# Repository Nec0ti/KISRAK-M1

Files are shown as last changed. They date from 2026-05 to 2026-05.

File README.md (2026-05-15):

# KISRAK-M1 Motor Driver

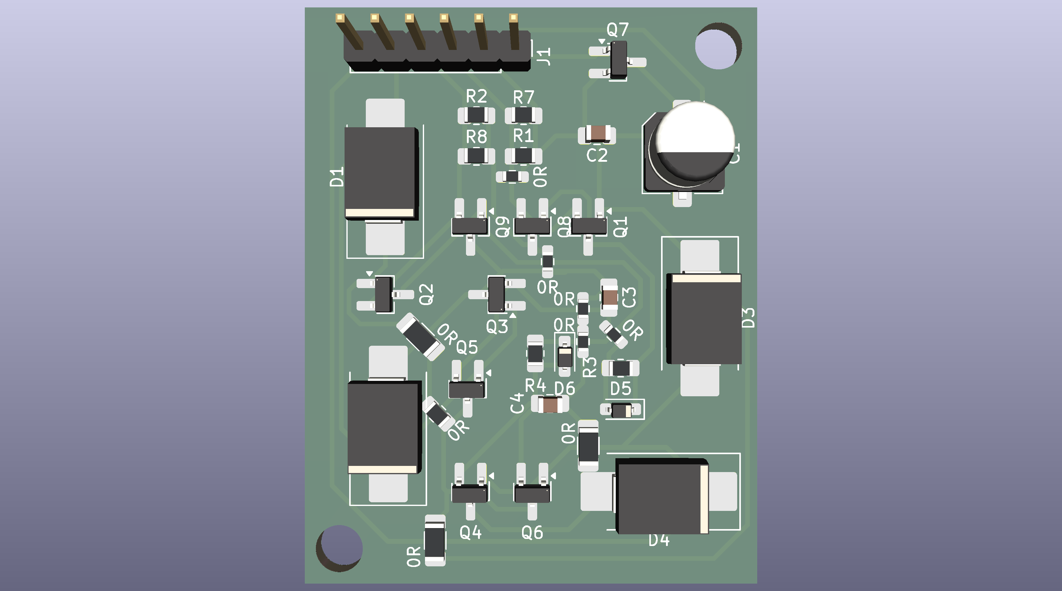
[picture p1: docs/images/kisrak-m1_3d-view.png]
KISRAK-M1 3D View


KISRAK-M1 is a high-efficiency, discrete H-Bridge motor driver designed for micro-robotics. 

## Technical Specifications
- **Type:** Discrete Complementary MOSFET H-Bridge.
- **MOSFETs:** UT2305G (P-Ch) & UTM2054G (N-Ch) logic-level pairs.
- **Logic Level:** 3.3V compatible (Tested with STM32).
- **Protection:** Passive Hardware Dead-Time & Reverse Polarity Protection.

## Passive Dead-Time Design
This project uses an RC-D circuit (47R, 2.2nF, 1N4148) to create asymmetrical switching times, preventing shoot-through without complex MCU PWM dead-time configuration.

## Documentation
For in-depth technical details, design philosophy, and fabrication guides, please refer to the [official documentation](docs/README.md).

## Micromouse Inspiration
To understand the competitive robotics context for which KISRAK-M1 is designed, watch this excellent overview of Micromouse competitions:

Micromouse Competition (https://www.youtube.com/watch?v=ZMQbHMgK2rw)

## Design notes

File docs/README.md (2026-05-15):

# KISRAK-M1 Documentation

Welcome to the official documentation for the KISRAK-M1 project. This document aims to provide a comprehensive and in-depth understanding of the KISRAK-M1 motor driver, covering its design philosophy, detailed hardware architecture, underlying physics, control mechanisms, fabrication guidelines, and validation procedures.

KISRAK-M1 is designed as a high-performance, open-source motor driver, specifically tailored for micro-robotic applications like Micromouse. My goal is not only to present "what" was built but also to elaborate on "why" specific design choices were made and the fundamental physical principles that govern its operation.

## Table of Contents

*   [Executive Summary & Project Motivation](01-Executive-Summary/index.html)
*   [Detailed Hardware Architecture (Sub-Systems)](02-Hardware-Architecture/index.html)
*   [The Physics of Dead-Time (Deep Dive)](03-Dead-Time-Physics/index.html)
*   [Signal Control & Firmware Interfacing](04-Signal-Control/index.html)
*   [DIY Fabrication & Reliability](05-DIY-Fabrication/index.html)
*   [Test & Validation](06-Test-Validation/index.html)

---
*This documentation is a living document and will be continuously updated.*

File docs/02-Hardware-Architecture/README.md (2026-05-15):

# 02 - Detailed Hardware Architecture (Sub-Systems)

This section delves into the intricate details of the KISRAK-M1's hardware architecture, breaking down each sub-system and explaining the design choices and their implications.

## Table of Contents

*   [Power Stage: MOSFET Selection and Thermal Efficiency](01-Power-Stage.html)
*   [Driver Stage: Totem-Pole Gate Drive](02-Driver-Stage.html)
*   [Protection Systems: Reverse Polarity and Inductive Kickback](03-Protection-Systems.html)

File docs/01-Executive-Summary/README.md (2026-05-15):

# 01 - Executive Summary & Project Motivation

This section provides an overview of the KISRAK-M1 project, outlining its core motivations, design philosophy, and the rationale behind key architectural decisions.

## Table of Contents

*   [Motor Driver Limitations in Robotics](01-Motor-Driver-Limits.html)
*   [KISRAK-M1's Micromouse Design Philosophy](02-Micromouse-Design-Philosophy.html)
*   [Why Discrete MOSFET Design?](03-Discrete-MOSFET-Choice.html)

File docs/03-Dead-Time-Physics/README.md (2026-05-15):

# 03 - The Physics of Dead-Time (Deep Dive)

Dead-time is a critical concept in H-bridge motor driver design. This section provides a deep dive into the physics behind dead-time, its calculation, and its importance in preventing shoot-through conditions.

## Table of Contents

*   [RC-D Circuit Time Constant Calculations](01-RC-D-Calculations.html)
*   [Asymmetric Switching: Rise Time vs. Fast Discharge](02-Asymmetric-Switching.html)
*   [Cross-Conduction (Shoot-through) Risk Analysis](03-Cross-Conduction-Analysis.html)

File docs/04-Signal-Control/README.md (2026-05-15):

# 04 - Signal Control & Firmware Interfacing

This section focuses on the control aspects of the KISRAK-M1, including PWM signal generation, duty cycle calculations, and how the driver interfaces with microcontrollers.

## Table of Contents

*   [PWM Frequency Selection (8kHz - 20kHz)](01-PWM-Frequency-Selection.html)
*   [Duty Cycle and Average Voltage Calculation](02-Duty-Cycle-Voltage.html)
*   [Control Logic Table for MCUs](03-Control-Logic-Table.html)

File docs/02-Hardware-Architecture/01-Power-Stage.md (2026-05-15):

# Power Stage: MOSFET Selection and Thermal Efficiency

The power stage of the KISRAK-M1 motor driver is a critical component, directly responsible for delivering current to the motor. It utilizes a full H-bridge configuration built with discrete P-Channel (UT2305G) and N-Channel (UTM2054G) MOSFETs. The selection of these specific MOSFETs is driven by a careful balance of performance, efficiency, and cost, with a strong emphasis on minimizing power losses and managing thermal dissipation.

## MOSFET Selection Criteria:

1.  **Voltage Rating ($V_{DS}$):** The drain-source voltage rating must be sufficiently higher than the maximum expected battery voltage to provide a safety margin against voltage spikes and transients. For KISRAK-M1, operating typically from a 1S or 2S LiPo battery (3.7V - 8.4V nominal), MOSFETs with a $V_{DS}$ rating of 20V or 30V are generally suitable. The UT2305G (P-Channel) and UTM2054G (N-Channel) both offer a 20V rating, providing an adequate margin.
2.  **Current Rating ($I_D$):** The continuous drain current rating must exceed the maximum expected motor current. Micromouse motors can draw significant peak currents during acceleration. The selected MOSFETs offer continuous drain currents (e.g., UT2305G: -4.6A, UTM2054G: 5.3A at $V_{GS}=4.5V$), which are sufficient for typical Micromouse applications, especially when considering the pulsed nature of PWM.
3.  **Gate-Source Voltage ($V_{GS}$):** The MOSFETs must be fully turned on (saturated) by the gate drive voltage provided by the microcontroller or gate driver. Both selected MOSFETs are "logic-level" compatible, meaning they can be fully turned on with a $V_{GS}$ as low as 2.5V or 4.5V, making them suitable for direct driving from a 3.3V or 5V microcontroller.
4.  **Gate Charge ($Q_g$):** This parameter is crucial for switching losses. A lower gate charge means less energy is required to charge and discharge the gate capacitance, leading to faster switching times and reduced switching losses, especially at higher PWM frequencies.
5.  **On-State Resistance ($R_{DS(on)}$):** This is arguably the most critical parameter for thermal efficiency in the power stage.

## The Impact of $R_{DS(on)}$ on Thermal Efficiency:

$R_{DS(on)}$ is the resistance between the drain and source terminals of a MOSFET when it is fully turned on. When current flows through the MOSFET in its on-state, power is dissipated as heat due to this resistance. This power loss is calculated by:

$$P_{conduction} = I_D^2 \times R_{DS(on)}$$

Where:
*   $P_{conduction}$ is the power dissipated as heat due to conduction.
*   $I_D$ is the drain current flowing through the MOSFET.
*   $R_{DS(on)}$ is the on-state resistance.

**Why lower $R_{DS(on)}$ is crucial:**

*   **Reduced Heat Generation:** A lower $R_{DS(on)}$ directly leads to less power being converted into heat for a given current. This is vital for compact designs like KISRAK-M1, where heat dissipation can be challenging.
*   **Improved Efficiency:** Less power lost as heat means more power delivered to the motor, increasing the overall efficiency of the motor driver. This translates to longer battery life and better performance.
*   **Prevention of Thermal Runaway:** Excessive heat can increase $R_{DS(on)}$ (for N-channel MOSFETs, $R_{DS(on)}$ typically increases with temperature), leading to a positive feedback loop where more heat generates more resistance, leading to even more heat. This can eventually destroy the MOSFET. Selecting MOSFETs with very low $R_{DS(on)}$ helps mitigate this risk.
*   **Smaller Heatsinking Requirements:** With less heat generated, the need for large heatsinks or extensive copper pours for thermal dissipation is reduced, allowing for a more compact PCB design.

### Selected MOSFETs:

*   **P-Channel MOSFET (High-Side): UT2305G**
    *   $V_{DS}$: -20V
    *   $I_D$: -4.6A
    *   $R_{DS(on)}$: 45mΩ @ $V_{GS}=-4.5V$, 65mΩ @ $V_{GS}=-2.5V$
    *   Datasheet: [UT2305G Datasheet](../datasheets/ut2305g-datasheet.pdf)

*   **N-Channel MOSFET (Low-Side): UTM2054G**
    *   $V_{DS}$: 20V
    *   $I_D$: 5.3A
    *   $R_{DS(on)}$: 25mΩ @ $V_{GS}=4.5V$, 35mΩ @ $V_{GS}=2.5V$
    *   Datasheet: [UTM2054G Datasheet](../datasheets/utm2054g-datasheet.pdf)

The chosen MOSFETs offer a good balance of low $R_{DS(on)}$ for their package size (SOT-23), sufficient current and voltage ratings, and logic-level compatibility, making them ideal for the KISRAK-M1's high-performance, compact design. The difference in $R_{DS(on)}$ between P-channel and N-channel MOSFETs is typical, as P-channel devices generally have higher on-resistance for a given die size due to the lower mobility of holes compared to electrons. This is why N-channel MOSFETs are preferred for low-side switching where possible.

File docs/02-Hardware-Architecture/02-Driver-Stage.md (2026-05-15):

# Driver Stage: Totem-Pole Gate Drive

The efficiency and reliability of a MOSFET H-bridge largely depend on how quickly and effectively the MOSFETs are switched between their ON and OFF states. This is the primary function of the gate driver stage. KISRAK-M1 employs a discrete **Totem-Pole gate driver** configuration using a complementary BJT pair (MMBT2222A NPN and MMBT2907A PNP) to manage the gate charge and discharge currents of the power MOSFETs.

<h2>The Need for a Gate Driver:</h2>

MOSFETs are voltage-controlled devices, but their gates exhibit significant capacitance ($C_{iss}$, $C_{rss}$, $C_{oss}$). To switch a MOSFET quickly, this gate capacitance must be charged and discharged rapidly. The current required to do this is known as the **gate charge current**. A microcontroller's GPIO pin, while capable of providing a voltage, typically has limited current sourcing/sinking capability (e.g., a few tens of mA). This is often insufficient to charge/discharge the MOSFET gate capacitance quickly enough, leading to:

*   **Slow Switching Times:** Prolonged transitions between ON and OFF states.
*   **Increased Switching Losses:** During the transition, the MOSFET is neither fully ON (low $R_{DS(on)}$) nor fully OFF (high impedance), resulting in significant power dissipation ($P_{switching} = V_{DS} \times I_D \times t_{transition} \times f_{PWM}$).
*   **Excessive Heat Generation:** Higher switching losses contribute to overall heat, potentially leading to thermal runaway.

<h2>Totem-Pole Configuration:</h2>

The Totem-Pole driver acts as a current buffer, amplifying the weak signal from the microcontroller to provide the necessary high current pulses to the MOSFET gate.

<h3>How it Works:</h3>

A typical Totem-Pole driver consists of an NPN transistor (e.g., MMBT2222A) and a PNP transistor (e.g., MMBT2907A) arranged in series, with their collectors connected to the MOSFET gate.

*   **Turning ON the MOSFET (Charging the Gate):**
    *   When the input signal from the MCU goes HIGH, the NPN transistor (MMBT2222A) turns ON.
    *   The PNP transistor (MMBT2907A) turns OFF.
    *   Current flows from the supply voltage (e.g., 5V or 3.3V) through a current-limiting resistor (if present) and the NPN transistor into the MOSFET gate, rapidly charging its capacitance. This pulls the gate voltage HIGH, turning the MOSFET ON.

*   **Turning OFF the MOSFET (Discharging the Gate):**
    *   When the input signal from the MCU goes LOW, the NPN transistor turns OFF.
    *   The PNP transistor turns ON.
    *   The MOSFET gate capacitance rapidly discharges through the PNP transistor to ground. This pulls the gate voltage LOW, turning the MOSFET OFF.

<h3>Gate Charge/Discharge Currents:</h3>

The BJT pair in the Totem-Pole configuration can source and sink much higher currents than a typical MCU GPIO. For instance, the MMBT2222A and MMBT2907A can handle continuous collector currents of up to 600mA. This high current capability allows for very fast charging and discharging of the MOSFET gate capacitance.

The peak gate current ($I_{G,peak}$) can be approximated by Ohm's law during the charging/discharging phase, considering the gate driver's output impedance and any series gate resistors. A higher peak current leads to a faster voltage slew rate at the gate ($dV_{GS}/dt$), which in turn reduces the switching time.

<h2>Benefits of Totem-Pole Gate Drive in KISRAK-M1:</h2>

1.  **Fast Switching:** By providing high peak gate currents, the Totem-Pole driver ensures rapid charging and discharging of the MOSFET gates, minimizing switching losses.
2.  **Reduced Power Dissipation:** Faster transitions mean the MOSFET spends less time in the linear region, where it dissipates the most power. This significantly improves overall efficiency and reduces heat generation in the power MOSFETs.
3.  **Improved EMI Performance:** Sharper switching edges can sometimes lead to increased EMI, but controlled fast switching can also reduce the energy content in the switching transitions, which can be beneficial.
4.  **Robustness:** The discrete BJT solution is robust and can be tailored for specific voltage levels and current requirements.

<h3>Selected BJTs:</h3>

*   **NPN Transistor: MMBT2222A**
    *   $V_{CEO}$: 40V
    *   $I_C$: 600mA
    *   Datasheet: [MMBT2222A Datasheet](../datasheets/2n2222-datasheet.pdf)

*   **PNP Transistor: MMBT2907A**
    *   $V_{CEO}$: -40V
    *   $I_C$: -600mA
    *   Datasheet: [MMBT2907A Datasheet](../datasheets/2n2907-datasheet.pdf)

These general-purpose BJTs are well-suited for the Totem-Pole configuration, offering sufficient current handling and switching speed for the KISRAK-M1's gate drive requirements. The use of discrete BJTs also contributes to the educational value, allowing for a clear understanding of the gate drive mechanism.

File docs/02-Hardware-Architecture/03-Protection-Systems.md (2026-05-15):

# Protection Systems: Reverse Polarity and Inductive Kickback

Robust protection systems are paramount for the reliability and longevity of any motor driver, especially in applications where power sources can be inadvertently connected incorrectly or where inductive loads are switched rapidly. KISRAK-M1 incorporates two key protection mechanisms: reverse polarity protection and inductive kickback suppression.

## Q7 Reverse Polarity Protection:

Accidental reverse connection of the battery is a common mistake that can instantly destroy unprotected electronic circuits. KISRAK-M1 employs a P-Channel MOSFET (Q7) for reverse polarity protection, offering a more efficient solution than a simple series diode.

### Mechanism:

A P-Channel MOSFET is placed in series with the positive power supply line, with its drain connected to the battery's positive terminal and its source connected to the rest of the circuit's positive rail. The gate of the P-Channel MOSFET is connected to ground (or a voltage divider that ensures $V_{GS}$ is appropriate).

*   **Correct Polarity Connection:**
    *   When the battery is connected correctly, the positive terminal is at a higher potential than the gate (which is at ground).
    *   This creates a negative $V_{GS}$ (e.g., $V_{GS} = V_{gate} - V_{source} = 0V - V_{battery}$).
    *   If the magnitude of this negative $V_{GS}$ is greater than the MOSFET's threshold voltage ($V_{GS(th)}$), the P-Channel MOSFET turns ON, allowing current to flow from the battery to the circuit.
    *   The MOSFET's body diode will conduct initially, and once the MOSFET turns on, current flows through the channel, bypassing the body diode and significantly reducing voltage drop and power loss compared to a standard diode.

*   **Reverse Polarity Connection:**
    *   When the battery is connected in reverse, the positive terminal of the battery (now effectively ground) is connected to the drain, and the negative terminal (now at a negative potential) is connected to the source.
    *   The gate is still at ground.
    *   In this scenario, the $V_{GS}$ becomes positive (e.g., $V_{GS} = V_{gate} - V_{source} = 0V - (-V_{battery}) = +V_{battery}$).
    *   A positive $V_{GS}$ keeps the P-Channel MOSFET firmly OFF.
    *   Crucially, the body diode of the P-Channel MOSFET will be reverse-biased, preventing current flow into the circuit. The circuit remains protected.

### Advantages over Series Diode:

*   **Lower Voltage Drop:** A P-Channel MOSFET in its ON state has a very low $R_{DS(on)}$, resulting in a minimal voltage drop across it (typically tens of millivolts). A standard silicon diode, in contrast, has a forward voltage drop of 0.7V or more, leading to significant power loss and heat generation, especially at higher currents.
*   **Higher Efficiency:** Reduced voltage drop means less power is wasted as heat, improving the overall efficiency of the system.
*   **Less Heat:** Lower power dissipation means less heat generated, simplifying thermal management.

## SS34 Schottky Diodes for Inductive Kickback Suppression:

Motors are inductive loads. When the current flowing through an inductor is rapidly switched off (e.g., when a MOSFET in the H-bridge turns off), the inductor resists this change by generating a large voltage spike (known as "inductive kickback" or "flyback voltage") with a polarity that tries to maintain the current flow. This voltage spike can easily exceed the breakdown voltage of the MOSFETs, leading to their destruction.

KISRAK-M1 utilizes SS34 Schottky diodes as **freewheeling diodes** (also known as flyback diodes or snubber diodes) to protect the MOSFETs from these destructive voltage spikes.

### Mechanism:

In an H-bridge, each MOSFET has a freewheeling diode connected in parallel, but in reverse bias across its drain and source. When a MOSFET turns off, and the motor's inductance tries to maintain current flow, the voltage across the MOSFET rises. As soon as this voltage exceeds the forward voltage of the freewheeling diode, the diode turns ON, providing a path for the inductive current to circulate. This clamps the voltage across the MOSFET to a safe level (approximately $V_{supply} + V_{diode\_forward\_drop}$).

### Why Schottky Diodes (SS34)?

Schottky diodes are preferred over standard silicon diodes for freewheeling applications due to their:

1.  **Low Forward Voltage Drop ($V_F$):** SS34 has a typical $V_F$ of around 0.5V. A lower $V_F$ means less power is dissipated in the diode itself and, more importantly, the voltage spike seen by the MOSFET is clamped to a lower value, providing better protection.
2.  **Fast Recovery Time:** Schottky diodes have very fast reverse recovery times (ideally zero). This is crucial in high-frequency PWM applications, as it prevents current spikes during the transition when the diode switches from conducting to blocking. A slow recovery diode can momentarily act as a short circuit, leading to shoot-through or increased switching losses.

### Inductive Kickback Suppression Mathematics:

The energy stored in an inductor is given by:
$$E_L = \frac{1}{2} L I^2$$
Where:
*   $E_L$ is the stored energy in Joules.
*   $L$ is the inductance in Henrys.
*   $I$ is the current in Amperes.

When the switch opens, this energy must be dissipated. Without a freewheeling diode, the voltage across the switch can rise to very high levels, limited only by parasitic capacitances and the breakdown voltage of the switch. With a freewheeling diode, the inductive current is diverted through the diode and the power supply (or another part of the H-bridge), dissipating the energy safely.

The voltage across the MOSFET when the diode conducts will be approximately:
$$V_{MOSFET} \approx V_{supply} + V_{F(diode)}$$
This ensures that the MOSFET's $V_{DS}$ rating is not exceeded.

### Selected Schottky Diode: SS34

*   $V_{RRM}$: 40V
*   $I_F$: 3A
*   $V_F$: 0.5V @ 3A
*   Datasheet: [SS34 Datasheet](../datasheets/ss34-datasheet.pdf)

The SS34 provides excellent protection against inductive kickback due to its low forward voltage and fast switching characteristics, ensuring the longevity and reliability of the KISRAK-M1 motor driver.

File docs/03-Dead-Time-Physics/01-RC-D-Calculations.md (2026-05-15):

# RC-D Circuit Time Constant Calculations

In an H-bridge motor driver, **dead-time** is a crucial concept referring to a short delay intentionally inserted between the turn-off of one MOSFET and the turn-on of its complementary MOSFET in the same half-bridge leg. This delay is essential to prevent **cross-conduction** (also known as shoot-through), a condition where both MOSFETs in a half-bridge are simultaneously ON, creating a direct short circuit across the power supply.

KISRAK-M1 implements a passive dead-time generation circuit using an RC-D (Resistor-Capacitor-Diode) network. This circuit, typically consisting of a 47Ω resistor, a 2.2nF capacitor, and a 1N4148 small signal diode, is placed in the gate drive path to introduce the necessary delay.

## The RC-D Network:

The RC-D circuit is designed to create an asymmetric delay in the gate signal.

*   **Resistor (R):** 47Ω
*   **Capacitor (C):** 2.2nF
*   **Diode (D):** 1N4148

### Time Constant ($\tau$) Calculation:

The fundamental characteristic of an RC circuit is its **time constant ($\tau$)**, which represents the time it takes for the capacitor voltage to reach approximately 63.2% of its final value during charging or to discharge to 36.8% of its initial value. It is calculated as:

$$\tau = R \times C$$

For the KISRAK-M1's RC-D circuit:
*   $R = 47 \, \Omega$
*   $C = 2.2 \, nF = 2.2 \times 10^{-9} \, F$

Therefore, the time constant is:
$$\tau = 47 \, \Omega \times 2.2 \times 10^{-9} \, F = 103.4 \times 10^{-9} \, s = 103.4 \, ns$$

This time constant of approximately 103.4 nanoseconds is a key parameter in determining the dead-time. It dictates the charging time of the capacitor, which in turn influences the turn-on delay of the MOSFET.

## Role of the Diode (1N4148):

The 1N4148 small signal diode is critical for creating the **asymmetric switching** behavior.

*   **Charging (Turn-ON Delay):** When the gate drive signal goes high, the capacitor charges through the resistor (R). The diode is reverse-biased during this phase (or has minimal effect if placed in parallel with R for charging), and the charging path is primarily through R and C. The time constant $\tau = R \times C$ governs this charging.
*   **Discharging (Turn-OFF Speed):** When the gate drive signal goes low, the capacitor needs to discharge quickly to turn off the MOSFET. The diode is placed in parallel with the resistor, but oriented to provide a low-resistance path for the discharge current, effectively bypassing the resistor. This allows the capacitor to discharge much faster than it charged, leading to a rapid turn-off.

The 1N4148 is a fast switching diode, which is important for ensuring that the discharge path is indeed low impedance and that the diode itself does not introduce significant delays.

## Importance of Dead-Time:

The calculated time constant and the asymmetric switching provided by the RC-D network directly contribute to the dead-time. This dead-time ensures that:

1.  One MOSFET is fully OFF before its complementary MOSFET begins to turn ON.
2.  This prevents shoot-through currents, which can damage the MOSFETs and waste significant power.

The precise value of dead-time is a trade-off. Too short, and shoot-through can occur. Too long, and efficiency can be reduced due to increased conduction losses in the body diodes of the MOSFETs during the dead-time period. The 103.4ns time constant provides a suitable delay for the chosen MOSFETs and switching frequencies in KISRAK-M1.

Datasheet for 1N4148: [1N4148WS Datasheet](../datasheets/1n4148ws-datasheet.pdf)

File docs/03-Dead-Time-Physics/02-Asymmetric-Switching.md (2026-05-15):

# Asymmetric Switching: Rise Time Delay vs. Fast Discharge Mechanism

The KISRAK-M1 motor driver employs an RC-D network in its gate drive stage to achieve **asymmetric switching**. This means that the turn-on time (rise time) of the MOSFET is intentionally made slower than its turn-off time (fall time). This asymmetry is a deliberate design choice to implement dead-time and prevent shoot-through, while still ensuring efficient operation.

## The RC-D Network for Asymmetry:

As discussed in the previous section, the RC-D circuit consists of a resistor (R), a capacitor (C), and a diode (D). The key to asymmetric switching lies in the diode's orientation and its interaction with the resistor and capacitor during charging and discharging cycles.

### 1. Rising Edge Delay (Slower Turn-ON):

When the input signal to the gate driver (from the MCU or a preceding stage) transitions from LOW to HIGH, the MOSFET gate needs to be charged to its turn-on threshold.

*   During this phase, the capacitor (C) charges through the resistor (R).
*   The diode (D) is typically reverse-biased or configured such that it does not provide a low-impedance path for charging.
*   The charging path is primarily defined by R and C, creating a time constant $\tau = R \times C$.
*   This RC time constant introduces a delay in the rising edge of the gate voltage, effectively slowing down the MOSFET's turn-on. The gate voltage will rise exponentially towards the supply voltage, taking several time constants to reach full turn-on.

This intentional delay in the turn-on of one MOSFET provides the necessary dead-time, ensuring that its complementary MOSFET in the half-bridge has sufficient time to fully turn off before the new MOSFET begins to conduct.

### 2. Fast Discharge Mechanism (Faster Turn-OFF):

When the input signal transitions from HIGH to LOW, the MOSFET gate needs to be rapidly discharged to turn the MOSFET off quickly.

*   During this phase, the capacitor (C) needs to discharge.
*   The diode (D) is now forward-biased, providing a low-resistance path for the discharge current. This path effectively bypasses the resistor (R).
*   Since the discharge path has a much lower equivalent resistance (primarily the forward resistance of the diode and the output impedance of the gate driver's sink stage), the capacitor discharges much faster.
*   This rapid discharge causes the gate voltage to fall quickly, leading to a fast turn-off of the MOSFET.

## Why Asymmetric Switching is Desirable:

1.  **Dead-Time Generation:** The primary reason for asymmetric switching is to create a reliable dead-time. By delaying the turn-on, I guarantee that there's a period where both MOSFETs in a half-bridge are OFF, preventing shoot-through.
2.  **Preventing Cross-Conduction:** A fast turn-off is crucial to quickly remove charge from the gate and ensure the MOSFET is non-conductive before its counterpart turns on. The slower turn-on then adds an additional safety margin.
3.  **Efficiency Considerations:** While a slower turn-on might seem counter-intuitive for efficiency (as it increases switching losses during turn-on), the overall benefit of preventing shoot-through (which causes catastrophic losses) far outweighs this. Moreover, the fast turn-off helps to minimize switching losses during the turn-off transition.
4.  **Miller Effect Mitigation:** During the turn-on transition, the MOSFET experiences the Miller effect, where the gate-drain capacitance ($C_{GD}$) is effectively multiplied, requiring more charge to change the gate voltage. A robust gate driver with asymmetric characteristics helps manage this by providing sufficient current for both charging and rapid discharging of the gate.

The 1N4148 diode, with its fast switching characteristics, is well-suited for this role, ensuring that the discharge path is indeed low impedance and that the diode itself does not introduce significant delays. This carefully engineered asymmetric switching ensures both the safety and efficiency of the KISRAK-M1 H-bridge.

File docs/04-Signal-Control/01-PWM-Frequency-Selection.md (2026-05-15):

# PWM Frequency Selection: Why 8kHz - 20kHz is Ideal

Pulse Width Modulation (PWM) is the fundamental technique I use in KISRAK-M1 to control the speed and direction of DC motors. The choice of PWM frequency is a critical design parameter that impacts motor performance, efficiency, audible noise, and electromagnetic interference (EMI). For KISRAK-M1, I have selected an ideal PWM frequency range of 8kHz to 20kHz based on a balance of these factors.

## Factors Influencing PWM Frequency Selection:

1.  **Audible Noise:**
    *   Human hearing typically ranges from 20Hz to 20kHz.
    *   PWM frequencies below 8kHz can often produce an audible whining or buzzing sound from the motor, which can be undesirable in many applications, especially in quiet environments or for user experience.
    *   By selecting a frequency above 8kHz, the switching noise is pushed towards the upper limit of human hearing, making it less noticeable or inaudible. Frequencies above 20kHz are generally considered ultrasonic and completely inaudible to humans.

2.  **Motor Inductance and Current Ripple:**
    *   DC motors are inductive loads. When a PWM voltage is applied, the motor's inductance smooths out the current, preventing it from rising and falling instantaneously.
    *   A higher PWM frequency results in a smaller current ripple (peak-to-peak variation in motor current).
    *   **Benefits of smaller current ripple:**
        *   **Reduced Motor Heating:** Large current ripples increase $I^2 R$ losses in the motor windings, leading to more heat.
        *   **Smoother Operation:** Less ripple results in smoother torque delivery and reduced vibrations.
        *   **Improved Efficiency:** Lower ripple current generally means better motor efficiency.
    *   However, excessively high frequencies can lead to increased switching losses in the MOSFETs (see point 3).

3.  **MOSFET Switching Losses:**
    *   Every time a MOSFET switches (turns ON or OFF), there are associated switching losses. These losses are proportional to the switching frequency.
    *   $$P_{switching} = (E_{on} + E_{off}) \times f_{PWM}$$
        Where $E_{on}$ and $E_{off}$ are the energy lost during turn-on and turn-off transitions, respectively.
    *   As the PWM frequency increases, switching losses increase. This generates more heat in the MOSFETs, potentially reducing efficiency and requiring more robust thermal management.
    *   A balance must be struck: high enough frequency for low audible noise and current ripple, but not so high that MOSFETs overheat.

4.  **Microcontroller Capabilities:**
    *   The chosen PWM frequency must be achievable by the microcontroller (MCU) generating the PWM signal. Most modern MCUs (like STM32) can easily generate PWM signals in the 8kHz-20kHz range with sufficient resolution (e.g., 8-bit or 10-bit duty cycle).
    *   Higher frequencies demand faster clock speeds and more sophisticated timer peripherals, which might limit duty cycle resolution.

5.  **Electromagnetic Interference (EMI):**
    *   Rapid switching of high currents can generate EMI. Higher frequencies can sometimes lead to more challenging EMI suppression, as the energy content shifts to higher frequency bands. However, well-controlled switching transitions (as achieved with the Totem-Pole driver) can help manage EMI.

## Why 8kHz - 20kHz is Ideal for KISRAK-M1:

*   **8kHz as a Lower Bound:** This frequency is generally considered the minimum to push most of the audible switching noise out of the most sensitive human hearing range. It provides a good balance for applications where some faint noise might be acceptable, but efficiency is paramount.
*   **20kHz as an Upper Bound:** This frequency is at the very edge of human hearing, making the motor virtually silent. It also provides a good balance with MOSFET switching losses for the chosen discrete components (UT2305G, UTM2054G) and their gate drive characteristics. Beyond 20kHz, the increase in switching losses often outweighs the benefits of further reduced current ripple or inaudibility for typical Micromouse motors.

This range ensures a quiet, efficient, and responsive motor control experience, perfectly suited for the demanding environment of Micromouse robotics. The KISRAK-M1's design, with its optimized gate drive, is capable of handling these frequencies effectively.

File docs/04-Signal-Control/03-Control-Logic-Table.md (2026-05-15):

# Control Logic Table for MCUs

Interfacing the KISRAK-M1 motor driver with a microcontroller (MCU) like an STM32 requires a clear understanding of the control signals needed to achieve desired motor movements. The KISRAK-M1 H-bridge is designed to be controlled by two PWM signals and two direction signals per motor, or a simplified two-pin control if the MCU can generate complementary PWM with dead-time. For simplicity and maximum flexibility, I'll consider a common four-pin control scheme per H-bridge, where two pins control the high-side MOSFETs and two pins control the low-side MOSFETs.

However, a more common and efficient approach for a full H-bridge is to use two PWM signals (one for each half-bridge) and two direction pins, or even just two PWM pins if the driver handles the complementary logic internally. Given the discrete nature of KISRAK-M1, the most direct control involves setting the gate signals for each of the four MOSFETs.

Let's define the control pins for one motor (one H-bridge):

*   `PWM_A`: Controls the high-side P-Channel MOSFET (e.g., Q1) and low-side N-Channel MOSFET (e.g., Q3) of one half-bridge.
*   `PWM_B`: Controls the high-side P-Channel MOSFET (e.g., Q2) and low-side N-Channel MOSFET (e.g., Q4) of the other half-bridge.

The KISRAK-M1 uses a complementary drive scheme where for each half-bridge, when the high-side P-channel is ON, the low-side N-channel is OFF, and vice-versa, with dead-time in between. The input to the Totem-Pole driver will determine the state of the MOSFETs.

Let's assume a simplified control where two input pins (`IN1`, `IN2`) from the MCU control the direction and speed of one motor. The internal logic of the KISRAK-M1 (via the Totem-Pole drivers and dead-time circuits) will then generate the appropriate gate signals for the four power MOSFETs.

## Simplified Control Logic (Two-Pin Input per Motor):

This table illustrates how two input pins from an MCU can control the direction and speed of a single motor connected to the KISRAK-M1 H-bridge. The PWM signal is applied to one of the input pins, while the other is held HIGH or LOW to set the direction.

| `IN1` (MCU Pin) | `IN2` (MCU Pin) | Motor Action |
| :--- | :--- | :--- |
| PWM | LOW | Motor rotates in Direction 1 (Speed controlled by PWM duty cycle) |
| LOW | PWM | Motor rotates in Direction 2 (Speed controlled by PWM duty cycle) |
| HIGH | HIGH | Motor Brake (Fast Decay / Short Brake) |
| LOW | LOW | Motor Freewheel (Coast / Slow Decay) |

### Explanation:

*   **PWM / LOW (Direction 1):** When `IN1` receives a PWM signal and `IN2` is held LOW, the H-bridge is configured to drive the motor in one direction. The duty cycle of the PWM on `IN1` determines the average voltage applied to the motor, thus controlling its speed.
*   **LOW / PWM (Direction 2):** Conversely, when `IN2` receives a PWM signal and `IN1` is held LOW, the motor rotates in the opposite direction, with speed controlled by the PWM on `IN2`.
*   **HIGH / HIGH (Fast Decay / Short Brake):** Both inputs HIGH effectively turns on both low-side MOSFETs (or high-side, depending on the exact internal logic of the driver stage), shorting the motor terminals. This provides a strong, rapid braking action by dissipating the motor's kinetic energy as heat in its windings.
*   **LOW / LOW (Slow Decay / Coast):** Both inputs LOW effectively turns off all active drive to the motor, allowing it to freewheel. The motor's back-EMF will circulate current through the freewheeling diodes and the low-side MOSFETs (if they are configured to be ON during this state), leading to a slower deceleration.

## Detailed Control Logic (Four-Pin Input per Motor - for direct gate control understanding):

For a deeper understanding, if the MCU were to directly control the gate drivers for each of the four MOSFETs in the H-bridge (assuming `GH1`, `GL1` for one half-bridge and `GH2`, `GL2` for the other, where `G` is Gate, `H` is High-side, `L` is Low-side, and 1/2 denote the half-bridge):

| `GH1` | `GL1` | `GH2` | `GL2` | Motor Action |
| :---- | :---- | :---- | :---- | :--- |
| PWM | LOW | LOW | HIGH  | Motor rotates in Direction 1 (Speed controlled by PWM) |
| LOW | HIGH  | PWM | LOW | Motor rotates in Direction 2 (Speed controlled by PWM) |
| LOW | HIGH  | LOW | HIGH  | Motor Brake (Fast Decay) |
| HIGH  | LOW | HIGH  | LOW | Motor Brake (Fast Decay) |
| LOW | LOW | LOW | LOW | Motor Freewheel (Coast) |

*Note: This table assumes active-high logic for N-channel MOSFETs and active-low for P-channel MOSFETs, and that the PWM is applied to the appropriate high-side or low-side switch for the desired direction. The actual implementation in KISRAK-M1 uses the Totem-Pole drivers to translate simpler MCU signals into the complex gate drive waveforms, including dead-time.*

Firmware developers should refer to the KISRAK-M1 schematic to understand the exact mapping of MCU pins to the driver's input signals. The simplified two-pin control per motor is generally preferred as it reduces the number of GPIOs required and offloads some of the complex timing (like dead-time generation) to the hardware.

This control logic forms the basis for implementing various motor control algorithms, including PID control for speed and position, crucial for high-performance robotic applications like Micromouse.

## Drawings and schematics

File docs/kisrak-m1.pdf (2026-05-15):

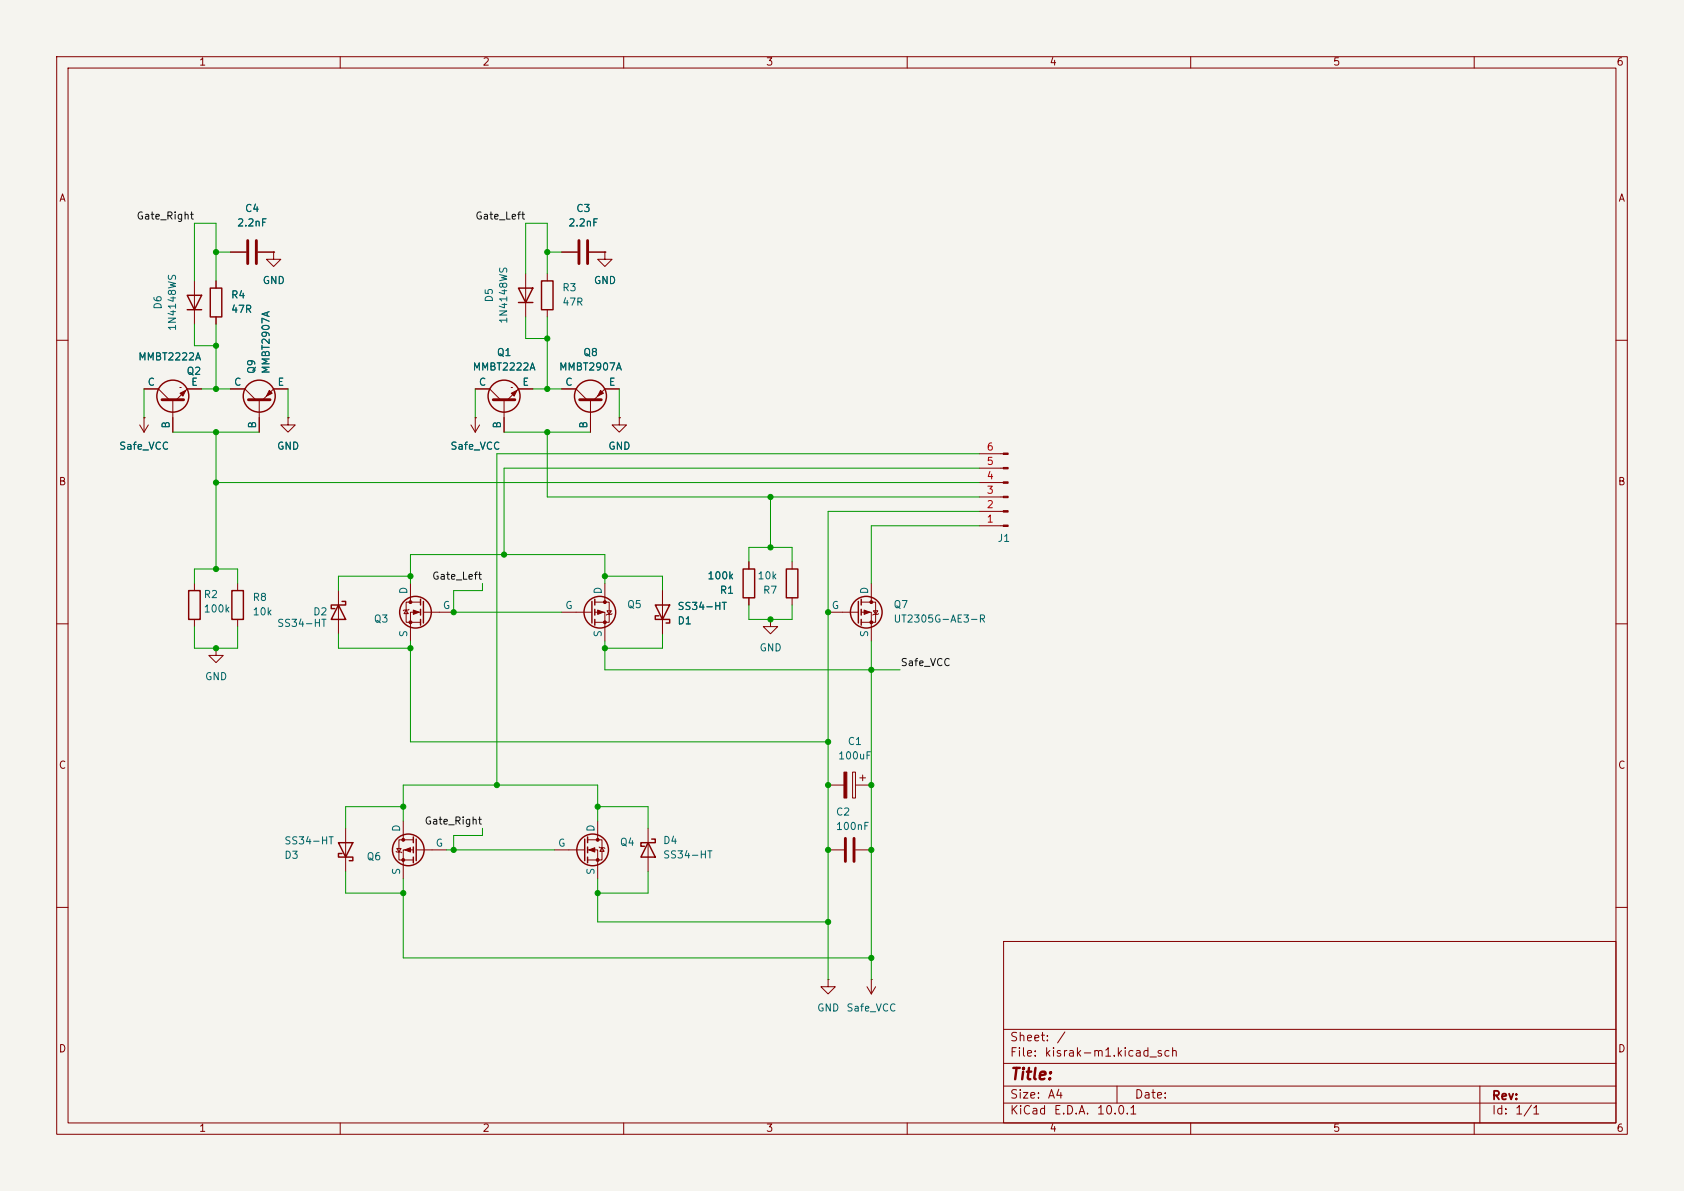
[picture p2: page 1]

Size: A4 | Rev:
KiCad E.D.A. 10.0.1 | Id: 1/1

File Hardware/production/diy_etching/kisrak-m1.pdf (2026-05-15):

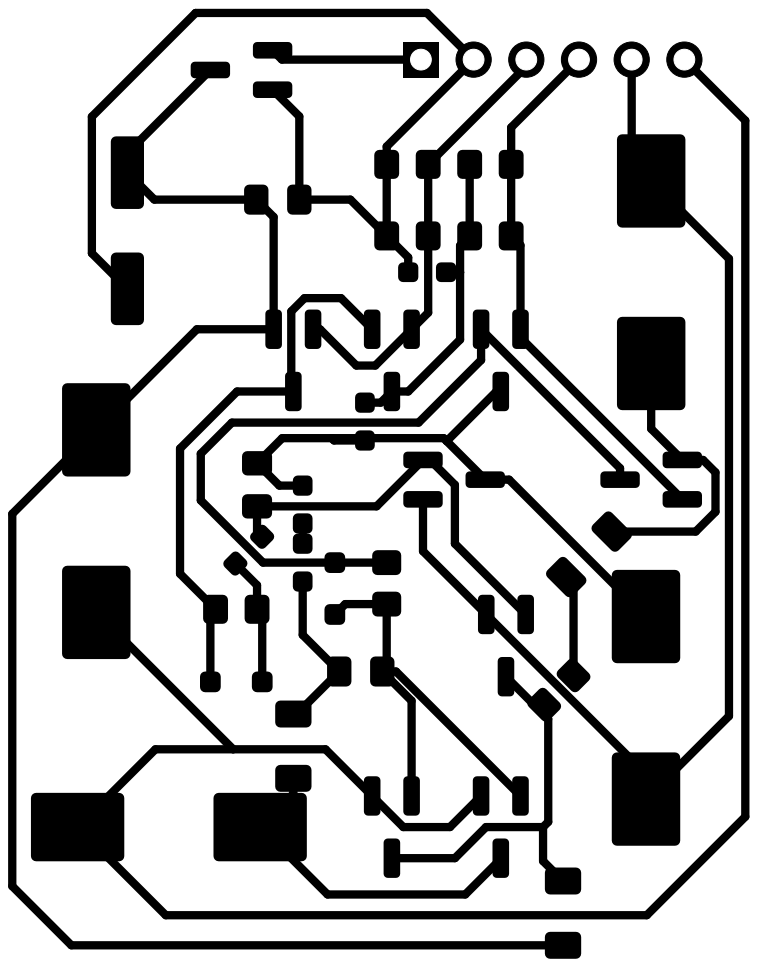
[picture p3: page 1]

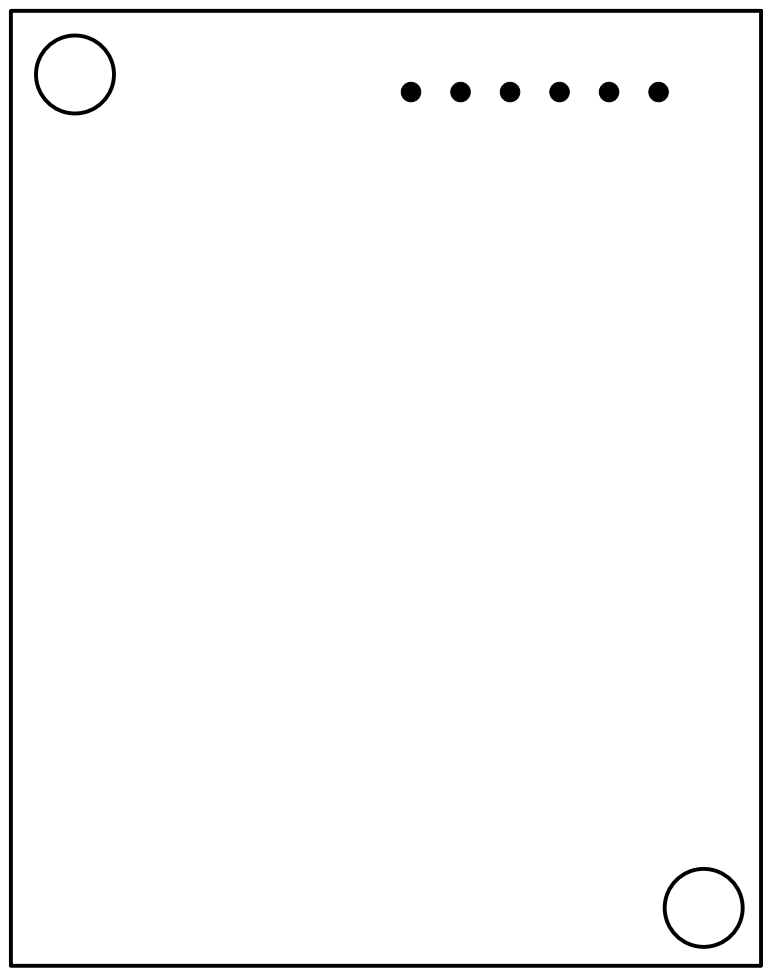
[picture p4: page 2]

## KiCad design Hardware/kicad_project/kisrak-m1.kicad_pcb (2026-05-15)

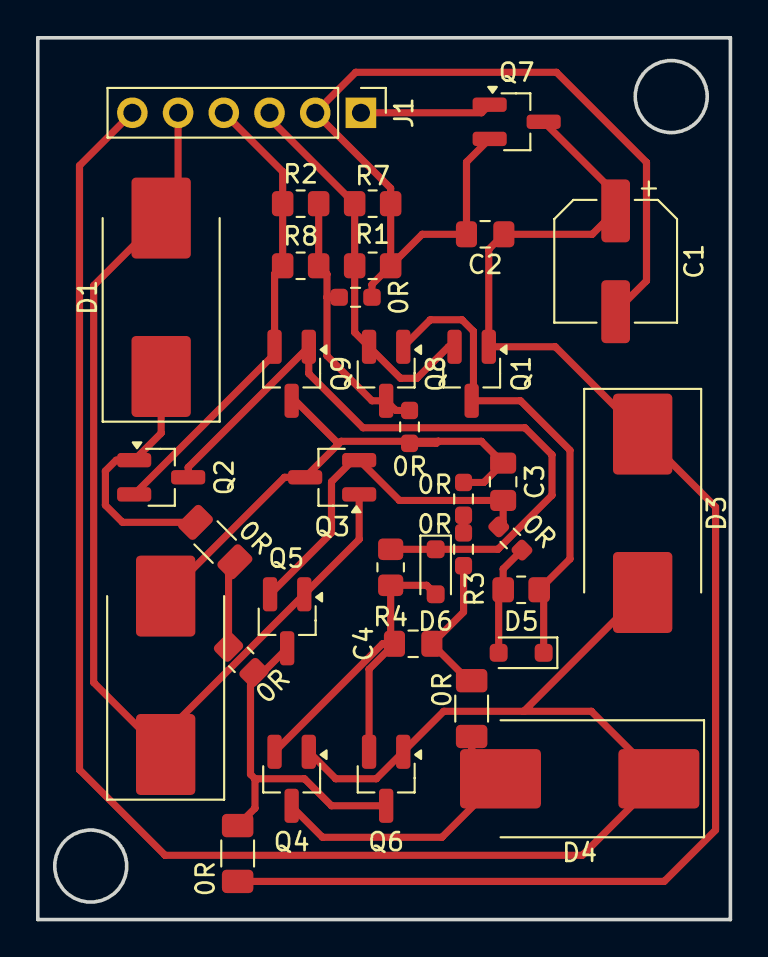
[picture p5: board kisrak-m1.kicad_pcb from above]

Board: 2 copper layers, 38.5 x 49.0 mm, 35 parts (0 on the bottom side), 11 nets.

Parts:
0R, 0R#6, 0R#7: R_1206_3216Metric_Pad1.30x1.75mm_HandSolder
0R#2, 0R#3, 0R#4, 0R#5, 0R#8: R_0603_1608Metric_Pad0.98x0.95mm_HandSolder
0R#9: R_0805_2012Metric_Pad1.20x1.40mm_HandSolder
C1: 100uF; CP_Elec_6.3x5.2
C2: 100nF; C_0805_2012Metric_Pad1.18x1.45mm_HandSolder
C3, C4: 2.2nF; C_0805_2012Metric_Pad1.18x1.45mm_HandSolder
D1, D2, D3, D4: SS34-HT; D_SMC_Handsoldering
D5, D6: 1N4148WS; D_SOD-323_HandSoldering
J1: PinHeader_1x06_P2.54mm_Vertical
Q1, Q2: MMBT2222A; SOT-23_Handsoldering
Q3, Q4: UTM2054G-AE3-R; SOT-23_Handsoldering
Q5, Q6, Q7: UT2305G-AE3-R; SOT-23_Handsoldering
Q8, Q9: MMBT2907A; SOT-23_Handsoldering
R1, R2: 100k; R_0805_2012Metric_Pad1.20x1.40mm_HandSolder
R3, R4: 47R; R_0805_2012Metric_Pad1.20x1.40mm_HandSolder
R7, R8: 10k; R_0805_2012Metric_Pad1.20x1.40mm_HandSolder

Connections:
/Gate_Left: 0R#8.1, 0R#8.2, C3.1, D5.2 (A), Q3.2 (G), Q5.2 (G), R3.1
/Gate_Right: C4.1, D6.2 (A), Q4.2 (G), Q6.2 (G), R4.1
GND: 0R.1, 0R.2, 0R#2.1, 0R#2.2, 0R#3.1, 0R#3.2, 0R#4.1, 0R#4.2, 0R#5.1, 0R#5.2, C1.2, C2.2, C3.2, C4.2, D2.2 (A), D4.2 (A), J1.2, Q3.3 (S), Q4.3 (S), Q7.2 (G), Q8.3 (E), Q9.3 (E), R1.1, R2.2, R7.1, R8.2
unnamed: D1.2 (A), D2.1 (K), J1.5, Q3.1 (D), Q5.1 (D)
unnamed: D3.2 (A), D4.1 (K), J1.6, Q4.1 (D), Q6.1 (D)
unnamed: D5.1 (K), Q1.3 (E), Q8.1 (C), R3.2
unnamed: D6.1 (K), Q2.3 (E), Q9.1 (C), R4.2
unnamed: J1.1, Q7.1 (D)
unnamed: J1.3, Q1.2 (B), Q8.2 (B), R1.2, R7.2
unnamed: J1.4, Q2.2 (B), Q9.2 (B), R2.1, R8.1
Safe_VCC: 0R#6.1, 0R#6.2, 0R#7.1, 0R#7.2, 0R#9.1, 0R#9.2, C1.1, C2.1, D1.1 (K), D3.1 (K), Q1.1 (C), Q2.1 (C), Q5.3 (S), Q6.3 (S), Q7.3 (S)

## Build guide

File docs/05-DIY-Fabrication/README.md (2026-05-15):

# 05 - DIY Fabrication & Reliability

KISRAK-M1 is designed with DIY fabrication in mind. This section provides guidelines and considerations for fabricating the PCB at home, focusing on reliability and best practices.

## Table of Contents

*   [Challenges of Single-Layer PCB Design & Ground Plane Strategy](01-Single-Layer-PCB-Challenges.html)
*   [Thermal Pad Design for Toner Transfer Etching](02-Thermal-Pad-Design.html)
*   [0.4mm Clearance Selection for Voltage Isolation](03-Clearance-Selection.html)

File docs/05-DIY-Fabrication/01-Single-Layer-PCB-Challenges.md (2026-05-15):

# Challenges of Single-Layer PCB Design & Ground Plane Strategy

Designing a Printed Circuit Board (PCB) for a motor driver, especially one handling significant currents, presents numerous challenges. These challenges are amplified when opting for a single-layer PCB, a common choice for DIY fabrication methods like toner transfer etching due to its simplicity and accessibility. KISRAK-M1 is designed to be single-sided, necessitating careful consideration of layout, current paths, and noise management.

## Inherent Challenges of Single-Layer PCB Design:

1.  **Routing Complexity:**
    *   All traces must be routed on a single copper layer. This often leads to complex, winding paths, especially for dense circuits with many interconnections.
    *   Crossing traces is impossible without using jumpers (wire bridges), which add manual assembly steps and can introduce parasitic inductance.
    *   Signal integrity can be compromised due to longer trace lengths and lack of direct return paths.

2.  **Grounding and Power Distribution:**
    *   Achieving a robust and low-impedance ground connection is difficult. A single-layer board often relies on thin traces for ground, which can lead to significant voltage drops (ground bounce) and noise coupling.
    *   Power distribution traces also suffer from higher impedance, leading to voltage drops under load.

3.  **Thermal Management:**
    *   Heat dissipation is less efficient compared to multi-layer boards where inner layers can act as thermal planes.
    *   Components that generate significant heat (like MOSFETs) require large copper areas for thermal relief, which can further complicate routing.

4.  **Electromagnetic Compatibility (EMC) / Electromagnetic Interference (EMI):**
    *   Lack of a continuous ground plane makes the board more susceptible to EMI and more likely to radiate noise.
    *   Long, thin traces act as antennas, both receiving and transmitting noise.
    *   Loop areas formed by signal and return paths can be large, increasing inductive coupling.

## KISRAK-M1's Ground Plane Strategy for Single-Layer PCB:

To mitigate the challenges, particularly those related to grounding and power distribution, I employ a strategic approach to ground plane design on my single-layer PCB.

1.  **Maximize Copper for Ground:**
    *   The most critical strategy is to dedicate as much available copper area as possible to the ground plane. After routing all signal and power traces, the remaining unused copper areas are filled with a ground pour.
    *   This creates a quasi-ground plane, providing a low-impedance return path for currents and helping to shield signals.

2.  **Star Grounding Principle (Modified):**
    *   While a true star ground is difficult on a single layer, the principle is applied by ensuring that high-current ground paths (e.g., from the motor, battery, and power stage MOSFETs) converge at a central, low-impedance point.
    *   This minimizes the sharing of high-current return paths with sensitive signal grounds, reducing noise coupling.

3.  **Wide Traces for Power and Ground:**
    *   All power and ground traces, especially those carrying high currents to and from the H-bridge and motor, are made as wide as possible.
    *   Wider traces reduce resistance ($R = \rho \frac{L}{A}$), thereby minimizing voltage drops and heat generation ($P = I^2 R$).
    *   They also increase current carrying capacity and reduce inductance.

4.  **Decoupling Capacitors:**
    *   Strategic placement of decoupling capacitors (e.g., 0.1uF ceramic) close to the power pins of active components (like the gate driver BJTs and the MCU if it were on the same board) helps to filter high-frequency noise and provide local current reservoirs, reducing ground bounce.
    *   Bulk capacitors (e.g., electrolytic) are placed near the power input and H-bridge to stabilize the main power rail.

5.  **Minimize Loop Areas:**
    *   Signal traces and their corresponding return paths are kept as close together as possible to minimize loop areas. Smaller loop areas reduce inductive coupling and EMI radiation.
    *   This is particularly important for the gate drive signals to the MOSFETs.

6.  **Component Placement:**
    *   Components are carefully placed to facilitate short, direct current paths, especially for the power stage.
    *   Sensitive analog signals are kept away from noisy digital or power switching sections.

By meticulously applying these strategies, KISRAK-M1 achieves a reliable and functional motor driver on a single-layer PCB, making it an excellent platform for DIY enthusiasts to build and understand. While not offering the same performance as a multi-layer board, it provides a robust solution within the constraints of accessible fabrication methods.

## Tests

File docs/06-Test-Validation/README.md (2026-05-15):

# 06 - Test & Validation

This section outlines the procedures for testing and validating the KISRAK-M1 motor driver, ensuring its proper functionality and performance.

## Table of Contents

*   [Initial Power-Up Protocol (Smoke Test)](01-Smoke-Test.html)
*   [Gate Signal Analysis with Oscilloscope](02-Gate-Signal-Analysis.html)

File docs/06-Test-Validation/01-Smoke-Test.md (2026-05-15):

# Initial Power-Up Protocol (Smoke Test)

After assembling any new electronic circuit, especially a power electronics board like the KISRAK-M1 motor driver, the very first power-up is a critical moment. This initial test is often referred to as a "smoke test" – the goal being to ensure that no magic smoke escapes from the components, indicating a catastrophic failure. A systematic approach is essential to prevent damage and ensure the board is safe for further testing.

## Objectives of the Smoke Test:

*   **Prevent Catastrophic Failure:** Identify major assembly errors (e.g., shorts, reversed components) before they cause permanent damage.
*   **Verify Basic Functionality:** Confirm that the power rails are stable and that the protection circuits are operational.
*   **Ensure Safety:** Protect both the circuit and the user from potential hazards.

## Recommended Smoke Test Protocol for KISRAK-M1:

**Tools Required:**
*   Current-limited DC power supply (highly recommended) or a battery with a series current-limiting resistor/fuse.
*   Digital Multimeter (DMM).
*   Magnifying glass or microscope (for visual inspection).

---

### Step 1: Thorough Visual Inspection (Power OFF)

Before applying any power, I perform a meticulous visual inspection of the entire assembled PCB.

*   **Solder Joints:** Check every solder joint for bridges, cold joints, or insufficient solder. Ensure all pins are properly connected.
*   **Component Orientation:** Verify the correct orientation of all polarized components:
    *   **Diodes:** Ensure the cathode band is in the correct position.
    *   **Electrolytic Capacitors:** Check polarity.
    *   **Integrated Circuits (if any):** Verify pin 1 orientation.
    *   **MOSFETs/BJTs:** Ensure they are not rotated 180 degrees.
*   **Short Circuits:** Look for any accidental solder bridges between adjacent pads or traces. Pay close attention to fine-pitch components.
*   **Cleanliness:** Ensure the board is free of solder balls, wire clippings, or other debris that could cause shorts.

---

### Step 2: Continuity Checks (Power OFF)

I use a DMM in continuity mode to perform several critical checks.

*   **Power Rail to Ground:**
    *   Place one DMM probe on the main power input (e.g., $V_{bat}$) and the other on ground.
    *   There should be NO continuity (open circuit or high resistance). A beep indicates a direct short, which MUST be resolved before proceeding.
    *   Repeat for any other power rails (e.g., 5V logic supply if present).
*   **Motor Outputs to Ground/Power:**
    *   Check for shorts between motor output terminals and ground or $V_{bat}$. There should be no direct shorts.
*   **Component Pins:**
    *   Verify continuity for critical connections (e.g., MOSFET gate to driver output, power pins of ICs).
    *   Check for shorts between adjacent pins of ICs or transistors.

---

### Step 3: Current-Limited Power-Up

This is the actual "smoke test" phase. **Crucially, I use a current-limited power supply.**

1.  **Set Power Supply:**
    *   Set the voltage to the lowest operating voltage (e.g., 3.7V for a 1S LiPo).
    *   Set the current limit to a very low value (e.g., 50mA - 100mA). This acts as a safety fuse.
2.  **Connect Power:** Connect the power supply to the KISRAK-M1's power input terminals, ensuring correct polarity.
3.  **Observe:**
    *   Carefully watch the power supply's current meter. If it immediately hits the current limit, there's likely a short circuit. Disconnect power immediately and re-inspect.
    *   Feel components for any signs of excessive heat. Any component getting hot quickly indicates a problem.
    *   Listen for any unusual sounds (e.g., buzzing, crackling).
    *   Smell for any burning odors.
4.  **Measure Voltages:**
    *   If no immediate issues are observed, I use the DMM to measure voltages at key points:
        *   Verify the voltage across the main power rails (e.g., $V_{bat}$ after the reverse polarity protection).
        *   Check the logic supply voltage (if applicable).
        *   Measure the voltage at the gate driver outputs (should be low or high depending on the default state).
5.  **Gradually Increase Voltage/Current Limit:**
    *   If all looks good, I slowly increase the voltage to the nominal operating voltage (e.g., 7.4V).
    *   I gradually increase the current limit to a higher, but still safe, value (e.g., 500mA - 1A).
    *   I continue to monitor current draw, component temperatures, and voltages. The quiescent current draw (with no motor connected and no PWM applied) should be very low (a few milliamps).

---

### Step 4: Test Protection Circuits (Optional but Recommended)

*   **Reverse Polarity Protection (Q7):** Briefly and carefully connect the power supply in reverse (with a very low current limit, e.g., 10mA). The circuit should draw virtually no current, and no components should heat up. This confirms Q7 is working. Immediately correct the polarity.

---

If the board passes the smoke test, it's ready for functional testing, starting with gate signal analysis. This methodical approach significantly reduces the risk of damaging components and provides confidence in the assembly quality.

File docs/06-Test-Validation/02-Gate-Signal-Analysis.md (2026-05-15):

# Gate Signal Analysis with Oscilloscope

After successfully completing the initial smoke test, the next crucial step in validating the KISRAK-M1 motor driver is to analyze the gate signals of the power MOSFETs using an oscilloscope. This analysis provides critical insights into the switching performance, dead-time implementation, and overall health of the gate drive stage.

## Objectives of Gate Signal Analysis:

*   **Verify Gate Drive Waveforms:** Ensure the gate signals are clean, have the correct voltage levels, and exhibit proper rise and fall times.
*   **Confirm Dead-Time:** Visually confirm the presence and duration of the dead-time between complementary MOSFETs in a half-bridge.
*   **Measure Rise/Fall Times:** Quantify the switching speed of the MOSFETs, which directly impacts switching losses and efficiency.
*   **Identify Issues:** Detect problems such as ringing, oscillations, insufficient gate voltage, or slow switching that could lead to inefficiency or damage.

## Tools Required:

*   **Oscilloscope:** A digital storage oscilloscope (DSO) with at least two channels and sufficient bandwidth (e.g., 100MHz or more).
*   **High-Impedance Probes:** Standard 10x passive probes are usually sufficient.
*   **Current-Limited DC Power Supply:** For safety during testing.
*   **Function Generator / Microcontroller:** To provide PWM signals to the KISRAK-M1 inputs.
*   **Small DC Motor (optional):** For testing under load, though initial tests can be done without a motor.

## Protocol for Gate Signal Analysis:

---

### Step 1: Setup and Initial Power-Up

1.  **Connect Power:** Connect the current-limited power supply to KISRAK-M1, set to a low operating voltage (e.g., 5V) and a safe current limit (e.g., 500mA).
2.  **Connect Function Generator/MCU:** Connect your function generator or microcontroller to the input pins of KISRAK-M1, configured to generate a low-frequency PWM signal (e.g., 1kHz - 5kHz) with a moderate duty cycle (e.g., 50%). This makes it easier to observe individual switching events.
3.  **Connect Oscilloscope Probes:**
    *   Connect the ground clip of both probes to a solid ground point on the KISRAK-M1 PCB, as close as possible to the MOSFETs being measured.
    *   **Probe 1:** Connect to the gate of a high-side P-Channel MOSFET (e.g., Q1).
    *   **Probe 2:** Connect to the gate of its complementary low-side N-Channel MOSFET (e.g., Q3) in the same half-bridge leg.

---

### Step 2: Observe and Analyze Gate Waveforms

1.  **Triggering:** Set the oscilloscope to trigger on one of the gate signals (e.g., rising edge of the low-side MOSFET gate).
2.  **Timebase and Vertical Scale:** Adjust the timebase (e.g., 1µs/div to 10µs/div) and vertical scale (e.g., 2V/div to 5V/div) to clearly see the full gate voltage swing and the switching transitions.
3.  **Expected Waveforms:**
    *   **Low-Side N-Channel MOSFET Gate (e.g., Q3):** Should swing from 0V to the gate drive voltage (e.g., 5V).
    *   **High-Side P-Channel MOSFET Gate (e.g., Q1):** Should swing from $V_{bat}$ (when OFF) down to $V_{bat} - V_{drive}$ (when ON). For example, if $V_{bat}=5V$ and drive is 5V, it would swing from 5V to 0V. If the drive is 3.3V, it would swing from 5V to 1.7V.
4.  **Key Measurements and Observations:**

    *   **Gate Voltage Levels:**
        *   Ensure the gate voltage swings fully between its ON and OFF states. For N-channel, typically 0V to $V_{drive}$. For P-channel, typically $V_{bat}$ to $V_{bat} - V_{drive}$.
        *   Insufficient gate voltage swing can lead to the MOSFET not fully turning ON, increasing $R_{DS(on)}$ and conduction losses.

    *   **Rise Time ($t_r$) and Fall Time ($t_f$):**
        *   Measure the time it takes for the gate voltage to rise from 10% to 90% of its final value (rise time) and fall from 90% to 10% (fall time).
        *   These times should be fast (typically in the tens to hundreds of nanoseconds) due to the Totem-Pole driver. Slower times indicate issues with the gate driver or excessive gate capacitance.

    *   **Dead-Time:**
        *   This is the most critical observation. Zoom in on the transition period where one MOSFET turns off and the other turns on.
        *   There should be a clear, measurable delay where both gate signals are in their OFF state (low for N-channel, high for P-channel).
        *   Measure this dead-time. It should correspond roughly to the calculated time constant of the RC-D network (e.g., ~100ns).
        *   **Absence of Dead-Time:** If the gate signals overlap (one turns on before the other fully turns off), it indicates a shoot-through condition, which is highly destructive. This requires immediate investigation of the RC-D circuit and gate driver.

    *   **Ringing and Oscillations:**
        *   Look for any excessive ringing or oscillations on the gate waveforms, especially during transitions. This can be caused by parasitic inductances and capacitances and can lead to false triggering or increased EMI. Minor ringing is often acceptable, but large, sustained oscillations are problematic.

---

### Step 3: Repeat for All Half-Bridges

Repeat the analysis for all half-bridges in the KISRAK-M1 driver to ensure consistent performance across all motor channels.

By meticulously performing gate signal analysis, I can confirm the proper operation of the KISRAK-M1's gate drive stage and dead-time implementation, which are fundamental to its efficiency and reliability. This step is indispensable for validating the hardware design.

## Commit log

2026-05-15 docs: added schematic pdf, etching masks and 3d renders
    [kisrak-m1-B_Adhesive.gbr, kisrak-m1-B_Cu.gbr, kisrak-m1-B_Paste.gbr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]
2026-05-15 feat: added BOM and finalized project structure for documentation
    [kisrak-m1.kicad_pcb, kisrak-m1.kicad_sch]
2026-05-15 docs: add board image to README
